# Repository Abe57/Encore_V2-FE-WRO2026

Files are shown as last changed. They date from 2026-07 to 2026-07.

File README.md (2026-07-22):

Encore | WRO-Futuros Ingenieros 2026 | PAN
====

Este es el repositorio oficial del equipo Encore V2. Somos representantes del colegio La Salle-Margarita en las regionales de Colón, Panamá de la World Robot Olympiad (WRO) 2026 en la categoría de Futuros Ingenieros.

La categoría de futuros ingenieros está enfocada en el diseño y la implementación de vehículos autónomos a escala. El desafío consiste en desarrollar un sistema capaz de navegar un circuito predefinido, identificando y superando obstáculos de forma autónoma mediante el procesamiento de datos de su entorno.

Esta disciplina está directamente alineada con las tendencias actuales y futuras de la industria automotriz, específicamente con el desarrollo de Sistemas Avanzados de Asistencia al Conductor (ADAS) y tecnologías de conducción autónoma. El proyecto de desarrollo exige una aplicación práctica de conceptos en áreas como la percepción ambiental, algoritmos de control y ingeniería de sistemas.

Nuestro proceso de desarrollo comenzó estratégicamente con un chasis prefabricado. Esta decisión nos permitió enfocarnos inicialmente en la integración de la electrónica y el desarrollo del software de control, sin la necesidad de conocimientos avanzados en diseño 3D. Sin embargo, pronto descubrimos que este punto de partida era solo el comienzo.

El verdadero desafío de ingeniería consistió en identificar sistemáticamente las limitaciones del diseño base y rediseñar cada subsistema para cumplir con nuestras exigentes expectativas de rendimiento. Desde la optimización del peso y la mecánica hasta la re-arquitectura completa del sistema eléctrico y de control, este robot es el resultado de un ciclo continuo de pruebas, diagnósticos y mejoras.

**Revise `docs` para ver la documentación completa y detallada, este `README.md` solo presenta un resumen de cada etapa del proyecto.**

## Equipo

Foto del equipo, de izquierda a derecha **José Heráldez, Abel Herrera y Pablo González**.
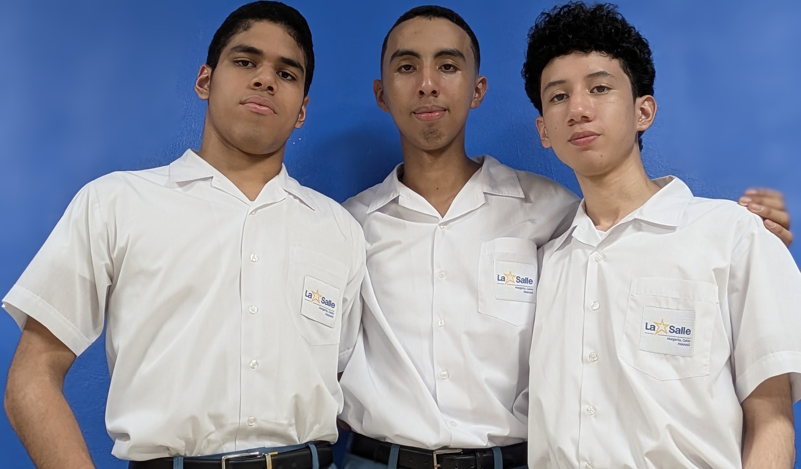
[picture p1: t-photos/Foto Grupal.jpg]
Foto equipo


## Contenido del Repositorio

* `docs` Contiene todos los documentos del equipo y el diario de ingeniería.
* `other` Otros archivos relacionados al desarrollo del robot.
* `schemes` Contiene los esquemas electromecánicos del vehículo y otros diagramas.
* `src` Contiene todos los programas que se estarán usando en la competencia.
* `t-photos` Contiene 2 fotos grupales (una formal y una divertida) y las fotos individuales.
* `v-photos` Contiene las 6 fotos desde todos los ángulos.
* `video` Contiene el video de demostración del funcionamiento del robot.

## Generalidades del robot

### 1. Vista Lateral Derecha
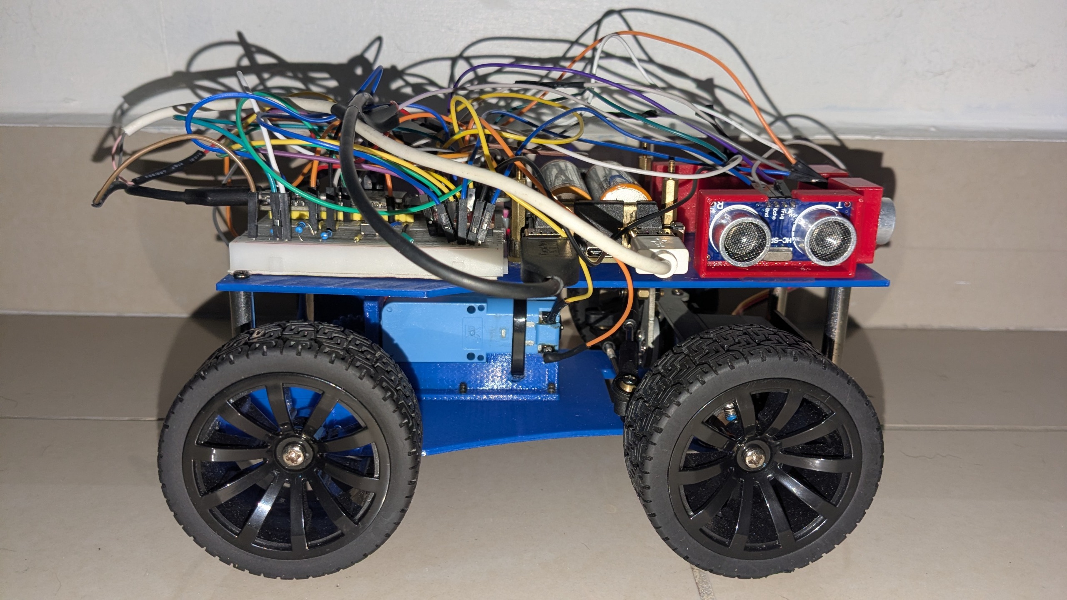
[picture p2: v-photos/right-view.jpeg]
Vista lateral derecha

*Vista del lado derecho del robot mostrando los componentes principales.*

### 2. Vista Frontal
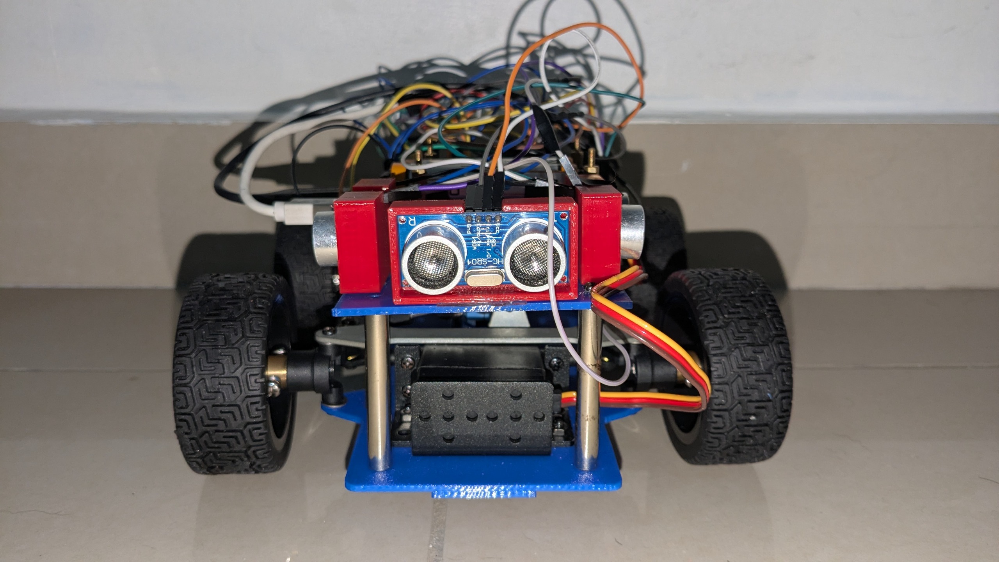
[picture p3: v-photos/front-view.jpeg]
Vista frontal

*Vista frontal del robot con los sensores de distancia y configuración delantera.*

### 3. Vista Lateral Izquierda
Vista lateral izquierda
*Vista del lado izquierdo del robot con los motores y estructura lateral.*

### 4. Vista Superior
Vista superior
*Vista desde arriba mostrando la distribución de componentes electrónicos y conexiones.*

### 5. Vista Trasera
Vista inferior
*Vista desde atras mostrando la transmisión.*

### 6. Vista Inferior
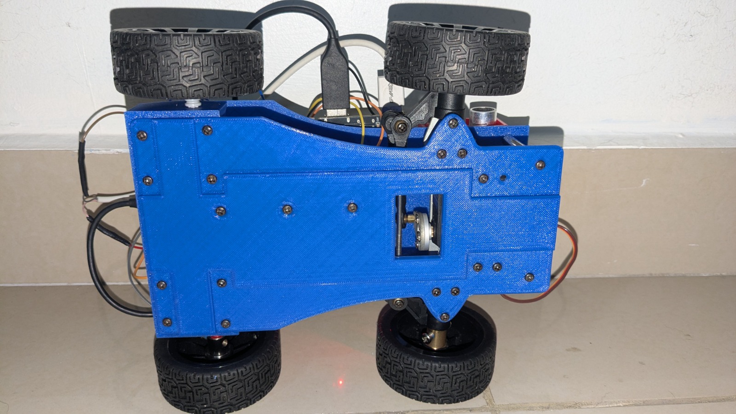
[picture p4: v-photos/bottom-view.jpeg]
Vista inferior

*Vista desde abajo mostrando la tornilleria y refuerzos estructurales.*

### Configuración general

El desarrollo del robot partió de un chasis Ackerman prefabricado para establecer una base mecánica sólida y acelerar el prototipado. Sin embargo, este punto de partida se convirtió en el primer desafío de ingeniería, ya que el diseño original presentaba problemas significativos de peso y una configuración de propulsión y dirección que requería un rediseño completo para cumplir con los objetivos de rendimiento del equipo.

### Descripción del chasis

El chasis original de metal, aunque resistente, elevaba el peso total del robot a 1700 g, una masa excesiva que limitaba la agilidad y sobrecargaba el sistema de propulsión. Para resolver esto, se llevó a cabo un proceso de optimización de materiales, reemplazando las placas de metal por diseños impresos en 3D. Esta modificación fue un éxito, reduciendo el peso total a aproximadamente 675 g y permitiendo un diseño más limpio y optimizado con perforaciones específicas para nuestros componentes. La estructura se mantuvo en dos niveles para aislar la electrónica de las vibraciones mecánicas.

### Sistema de dirección

Para lograr una navegación precisa, se implementó una geometría de dirección Ackerman. Este sistema, que minimiza el deslizamiento de las ruedas en las curvas, fue un diseño a medida del equipo. A través de un proceso de investigación y prototipado, se fabricaron soportes y se calibraron las varillas de acoplamiento para emular la cinemática ideal. El sistema es accionado por un servomotor de alto torque, asegurando que la dirección sea firme y responda con precisión a los comandos.

### Sistema de propulsión

El diseño inicial del sistema de propulsión priorizaba la velocidad con una relación de engranajes de 9:7 (sobremarcha). Sin embargo, las pruebas demostraron que el torque resultante era insuficiente para vencer la inercia y la fricción estática, impidiendo que el robot se moviera por sí solo. Tras diagnosticar el problema, se tomó la decisión de ingeniería de invertir la relación a una de reducción 7:9. Aunque esto sacrificó la velocidad máxima, multiplicó el torque, proporcionando la fuerza de arranque necesaria para un funcionamiento autónomo y fiable.

### Diseño Eléctrico

La arquitectura eléctrica evolucionó a un sistema compacto y eficiente para maximizar la confiabilidad del robot.

* ESP32 (Unidad de control principal): Actualmente se utiliza una ESP32 única, sin Arduino adicional, como cerebro del sistema. Se encarga de ejecutar la lógica de control, leer los sensores y gestionar los actuadores.

* Driver TB6612FNG: Sustituyó al L298N y se utiliza para controlar de forma eficiente los motores, mejorando la gestión de corriente y la estabilidad del sistema.

* Sensores HC-SR04: Se emplearon tres sensores ultrasónicos en la parte frontal para detectar obstáculos y medir distancias en tiempo real.

* Giroscopio BNO055: Se incorporó para obtener mediciones de orientación y mejorar la estabilidad del movimiento y la navegación del robot.

* Servo para el manejo: Se utiliza para controlar la dirección del vehículo de forma precisa y responsiva.
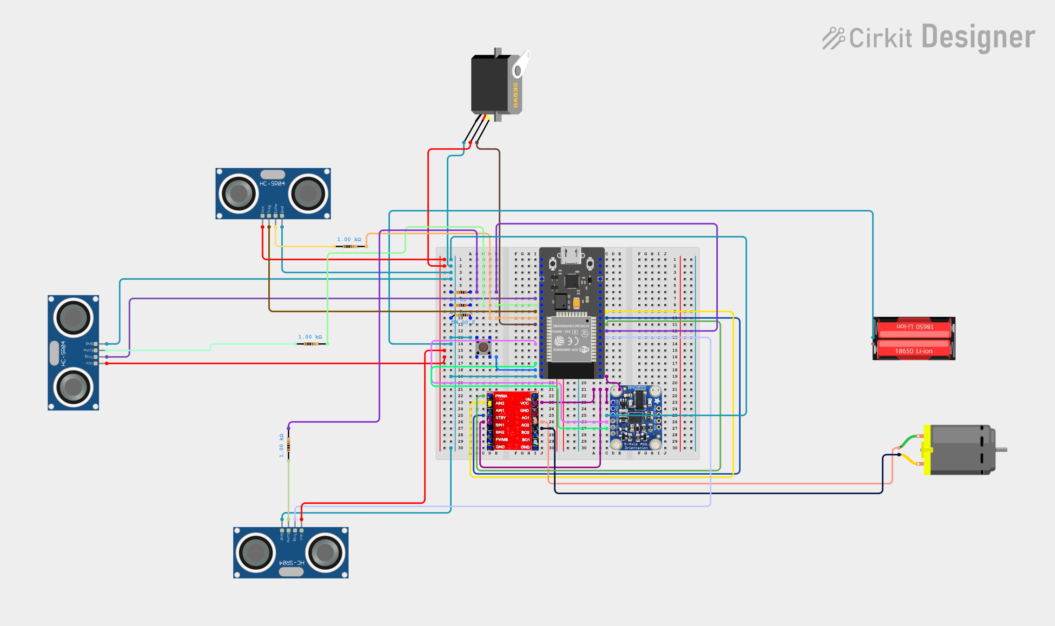
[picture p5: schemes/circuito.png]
imagen


### Gestión de la energía

La estabilidad energética se resolvió con un sistema de alimentación más simple y compacto:

* Un power bank de 10000mAh se utiliza para alimentar el motor y el servo.

* Dos baterías 18650 en conjunto proporcionan la energía necesaria para la ESP32, con salida de 5V para alimentar la unidad de control y sus periféricos. Esta configuración permite un funcionamiento estable y reduce la complejidad del sistema.

### Diseño del Código y Programación

La arquitectura del software se basa en un enfoque integrado en una sola placa de control:

* ESP32 (C++): Actúa como el cerebro principal del robot. Se encarga de la lectura de los sensores ultrasónicos, del giroscopio BNO055, de la lógica de decisión y del control de los actuadores, incluyendo los motores y el servo de dirección.

Este enfoque permite reducir la complejidad del sistema, minimizar puntos de fallo y mejorar la respuesta del robot en tiempo real.

### Demostración

Después de un arduo ciclo de desarrollo y pruebas, el robot es capaz de cumplir con los requisitos de la primera ronda, demostrando una navegación autónoma y la capacidad de detectar y esquivar obstáculos.

### Características por mejorar

Basado en los resultados de la primera competencia y las pruebas continuas, el equipo ha identificado las siguientes áreas clave para el desarrollo futuro:

* Reducir la Latencia del Bucle de Control: Optimizar el código y la comunicación interna entre la ESP32 y los actuadores para lograr reacciones más rápidas y una navegación más fluida.

* Mejorar la Fiabilidad de las Conexiones: Migrar las conexiones del protoboard a una solución más permanente, como una PCB diseñada a medida o una protoboard soldada, para eliminar los falsos contactos.

* Optimizar la Velocidad y el Control: Una vez que la fiabilidad esté garantizada, se trabajará en aumentar la velocidad máxima del robot y en refinar los algoritmos de control para una mayor precisión en el seguimiento de la trayectoria.

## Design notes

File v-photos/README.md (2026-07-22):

# Fotos del Robot WRO 2026

Este directorio contiene las 6 vistas principales del robot Encore V2 para la competencia WRO 2026.

## Vistas del Robot

### 1. Vista Lateral Derecha
Vista lateral derecha
*Vista del lado derecho del robot mostrando los componentes principales.*

### 2. Vista Frontal
Vista frontal
*Vista frontal del robot con los sensores de distancia y configuración delantera.*

### 3. Vista Lateral Izquierda
Vista lateral izquierda
*Vista del lado izquierdo del robot con los motores y estructura lateral.*

### 4. Vista Superior
Vista superior
*Vista desde arriba mostrando la distribución de componentes electrónicos y conexiones.*

### 5. Vista Trasera
Vista inferior
*Vista desde atras mostrando la transmisión.*

### 6. Vista Inferior
Vista inferior
*Vista desde abajo mostrando la tornilleria y refuerzos estructurales.*

## Componentes Principales Visibles

- Plataforma de chassís azul
- Motor DC con ruedas de tracción
- Sistema de sensores ultrasónicos HC-SR04
- Microcontrolador ESP32
- Baterías 18650 y módulo de distribución de potencia
- Cableado de conexión

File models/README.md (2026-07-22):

# Modelos 3D del robot

Este directorio contiene los diseños principales impresos en 3D del robot, incluyendo las estructuras base, los soportes de motor y eje, así como los soportes para los sensores ultrasónicos.

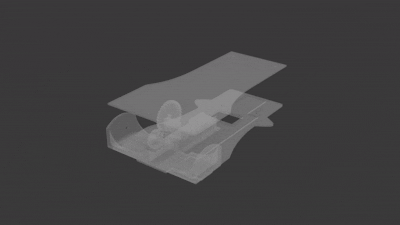
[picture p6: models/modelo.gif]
Modelo


## 1. Placa inferior
La placa inferior es la estructura base del robot. Presenta huecos para los tornillos del servo, los soportes, el soporte del motor y el soporte del eje. En su parte inferior cuenta con una extrusión que cubre la mayor parte de la placa, lo que le proporciona mayor grosor y estabilidad en las zonas donde más se necesita.

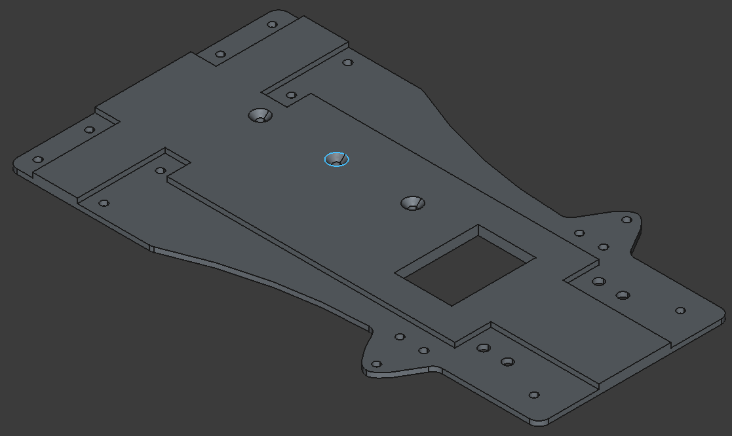
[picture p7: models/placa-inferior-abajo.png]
Placa inferior


## 2. Placa superior
La placa superior se conecta con la placa inferior mediante soportes, formando la estructura principal del chasis y permitiendo una distribución ordenada de los componentes del robot.

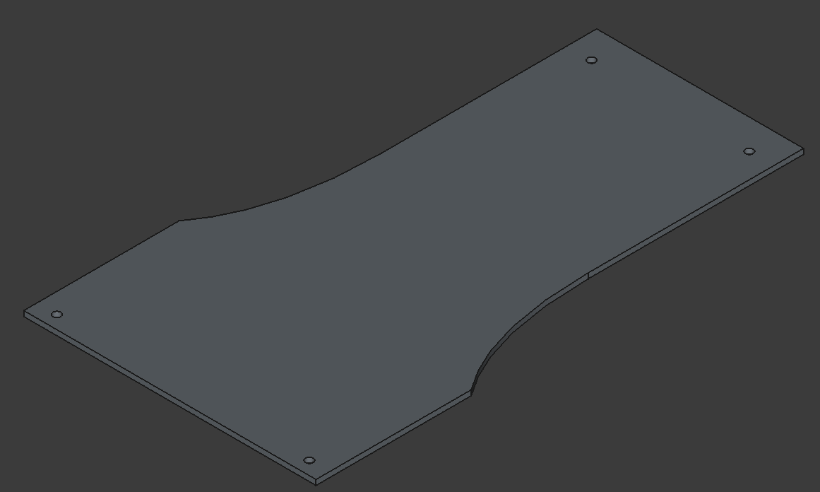
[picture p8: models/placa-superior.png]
Placa superior


## 3. Soporte del motor
El soporte del motor se atornilla directamente sobre los huecos diseñados en la placa inferior. Su función es mantener el motor en la posición óptima para un funcionamiento estable y eficiente.

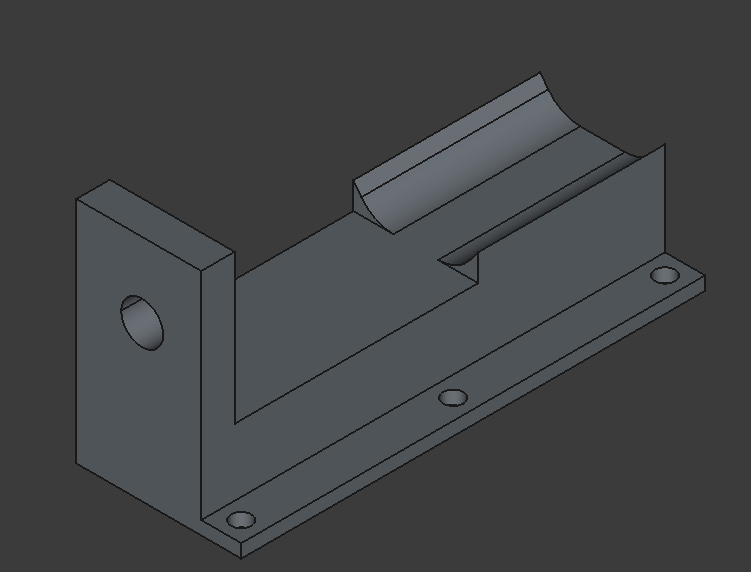
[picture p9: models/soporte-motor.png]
Soporte del motor


## 4. Soporte del eje
El soporte del eje sostiene el eje de manera que el engrane del eje y el engrane del motor giren de forma sincronizada. Está diseñado con soportes y bisagras para mejorar su resistencia y estabilidad.

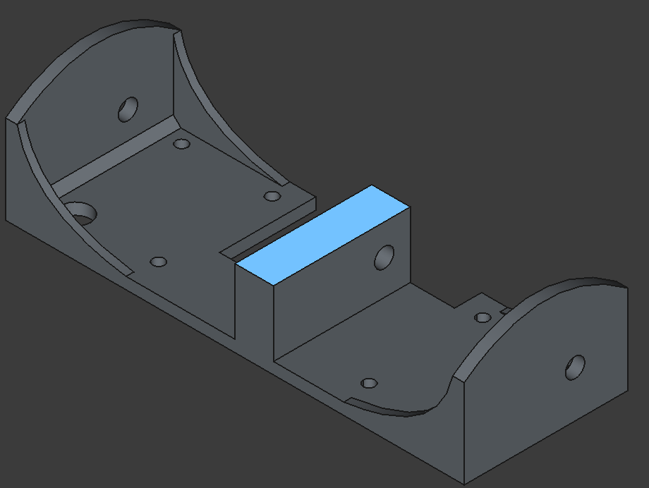
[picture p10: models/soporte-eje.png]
Soporte del eje


## 5. Soporte HC-SR04
Los soportes para los sensores HC-SR04 fueron obtenidos a partir del modelo de Printables: https://www.printables.com/model/657026-hc-sr04-ultrasonic-sensor-holder-for-orp. Estos soportes se colocan en la parte frontal del robot para sostener los sensores de forma segura y estable.

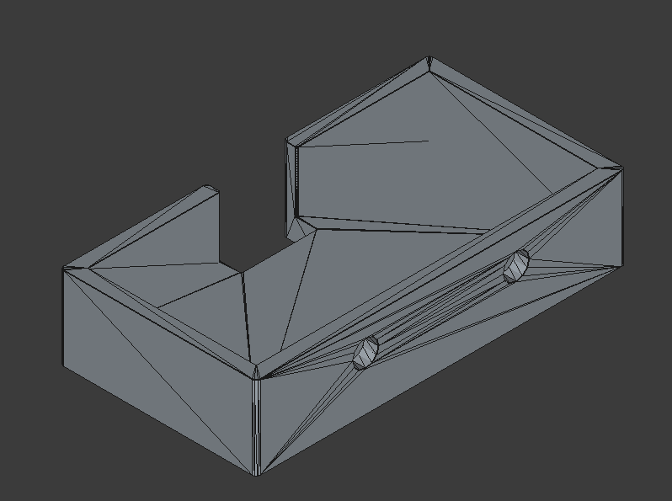
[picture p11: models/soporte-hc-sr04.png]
Soporte HC-SR04


## Engranes utilizados
Los engranes utilizados en el sistema de transmisión son de 36 dientes y 28 dientes de LEGO.

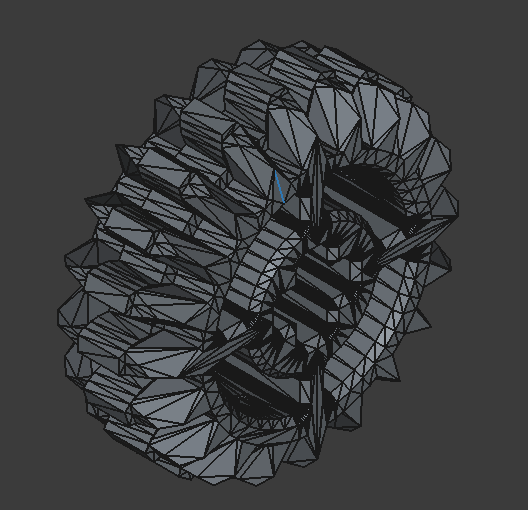
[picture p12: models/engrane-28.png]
Engrane 28 dientes


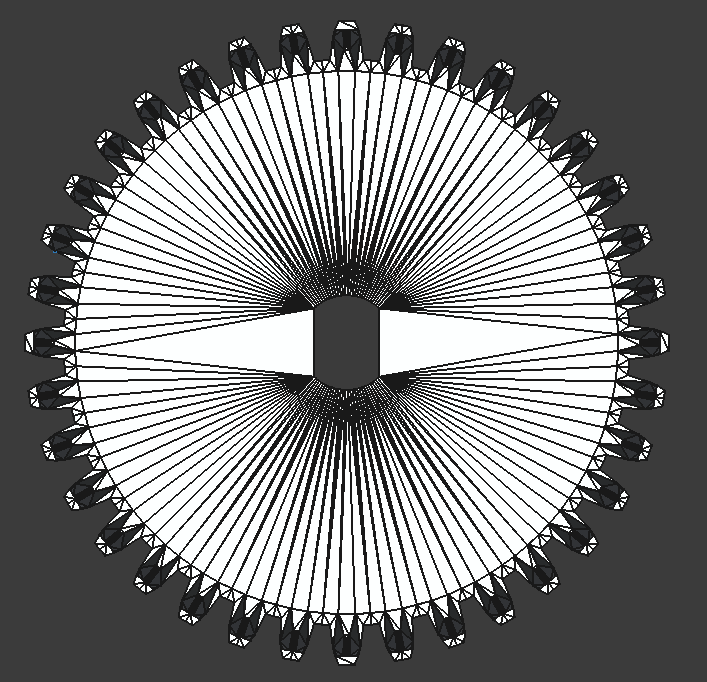
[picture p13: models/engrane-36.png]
Engrane 36 dientes


## Modificación del engrane de 36 dientes
El engrane de 36 dientes fue modificado para volverse sólido por dentro y adaptarse al motor, lo que mejora su compatibilidad y resistencia dentro del sistema mecánico.

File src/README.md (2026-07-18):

Control software
====

Este directorio contiene el software de control del vehículo utilizado para la competencia. El código principal se encuentra en el archivo `src/main/main.ino` y está pensado para operar de forma autónoma mediante sensores de distancia y un giroscopio.

## Descripción general

El programa implementa un sistema de control distribuido en dos tareas concurrentes ejecutadas en distintos núcleos del microcontrolador:

- `getSensors`: lee continuamente los sensores de proximidad y el giroscopio, y actualiza los valores de navegación usados por la lógica de control.
- `control`: gestiona la dirección del vehículo y toma decisiones para evitar obstáculos detectados por los sensores.

## Hardware involucrado

El sketch está diseñado para trabajar con:

- 3 sensores ultrasónicos (izquierdo, centro y derecho)
- Un giroscopio BNO055
- Un servomotor para la dirección
- Un driver de motores y dos pines de control de movimiento
- Un botón de inicio

## Funcionamiento del sistema

1. Al encender el sistema, se inicializan los sensores y el servo.
2. El programa espera a que se presione el botón de inicio.
3. Una vez iniciado, el robot intenta avanzar mientras el sensor central no detecte un obstáculo.
4. Si el sensor central detecta un objeto dentro del rango configurado, el sistema inicia una maniobra de giro.
5. La dirección se ajusta según la lectura del giroscopio para mantener una trayectoria controlada.
6. El algoritmo usa los sensores laterales para decidir si girar en sentido horario o antihorario.

## Variables principales

- `dMin` y `dMax`: rangos de distancia usados para detectar obstáculos y decidir cuando girar.
- `MAX_TURN`: límite de giro del servo.
- `cw`: indica la dirección del giro actual.
- `turnOffset`: ayuda a mantener el ángulo de referencia durante la maniobra.

## Notas de implementación

- El código utiliza `FreeRTOS` mediante `xTaskCreatePinnedToCore` para ejecutar tareas en núcleos separados.
- La comunicación serial se usa para depurar y monitorear los valores de los sensores en tiempo real.
- El servo se controla con la librería `ServoEasing`.

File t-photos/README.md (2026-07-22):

Fotos del Equipo
====

Foto del equipo **(De izquierda a derecha: Jose Heraldez, Abel Herrera, Pablo Gonzalez)**

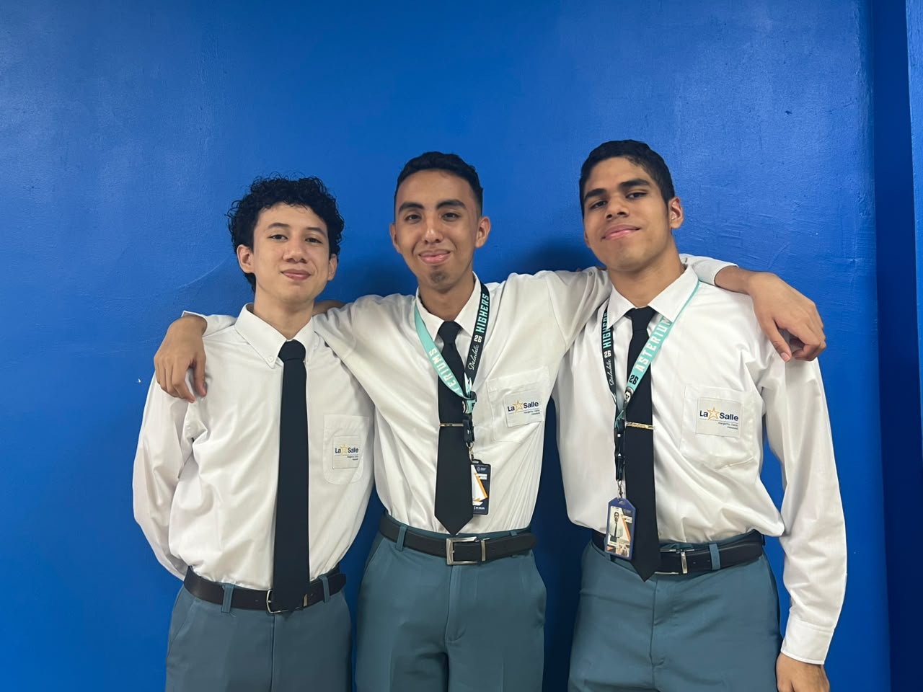
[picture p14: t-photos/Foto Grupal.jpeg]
Imagen Grupal Foto Grupal

Somos un grupo de amigos apasionados por la robotica y que cursamos el mismo grado, llevamos en las WRO desde 2023, este año vamos con el objetivo de sacar nuestro máximo potencial.

### José Heráldez
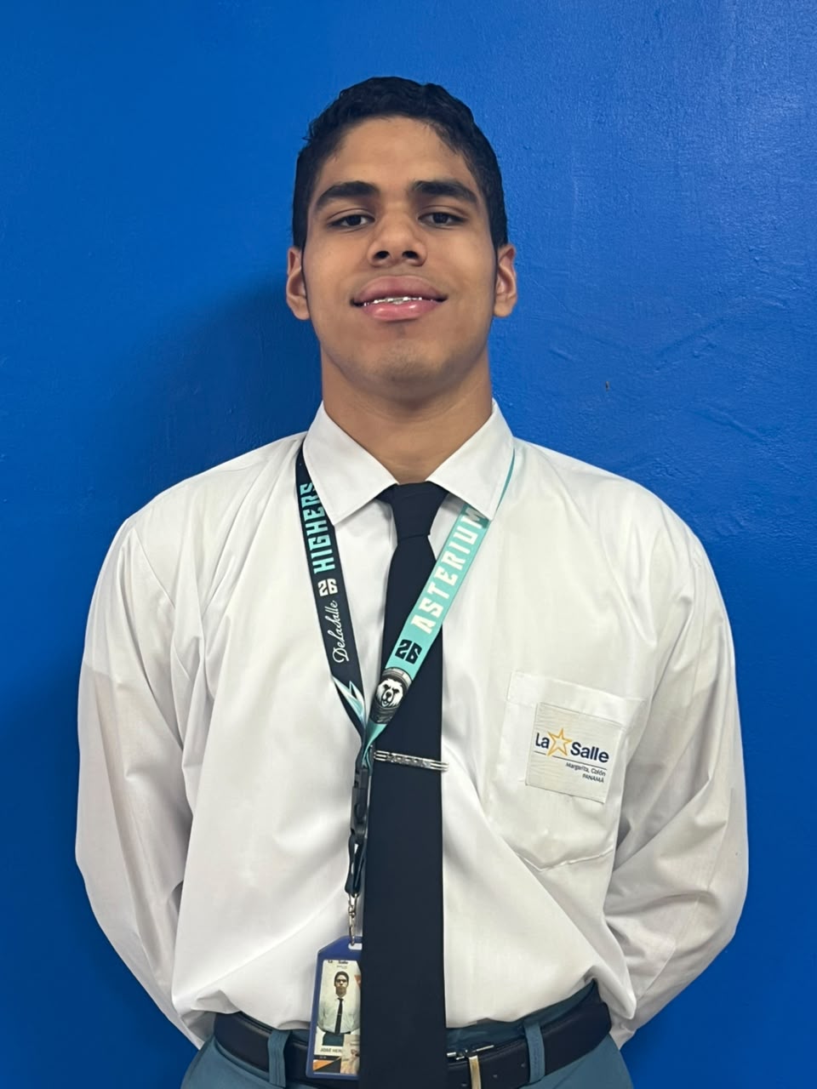
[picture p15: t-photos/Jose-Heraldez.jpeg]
José Heráldez


Es el coordinador y el apoyo general, se encarga de mantener toda la organización, reuniones, recopilación de información y redacción, es calmado, proactivo y tiene experiencia en gestión de proyectos y le gusta mantener el orden. 

### Abel Herrera
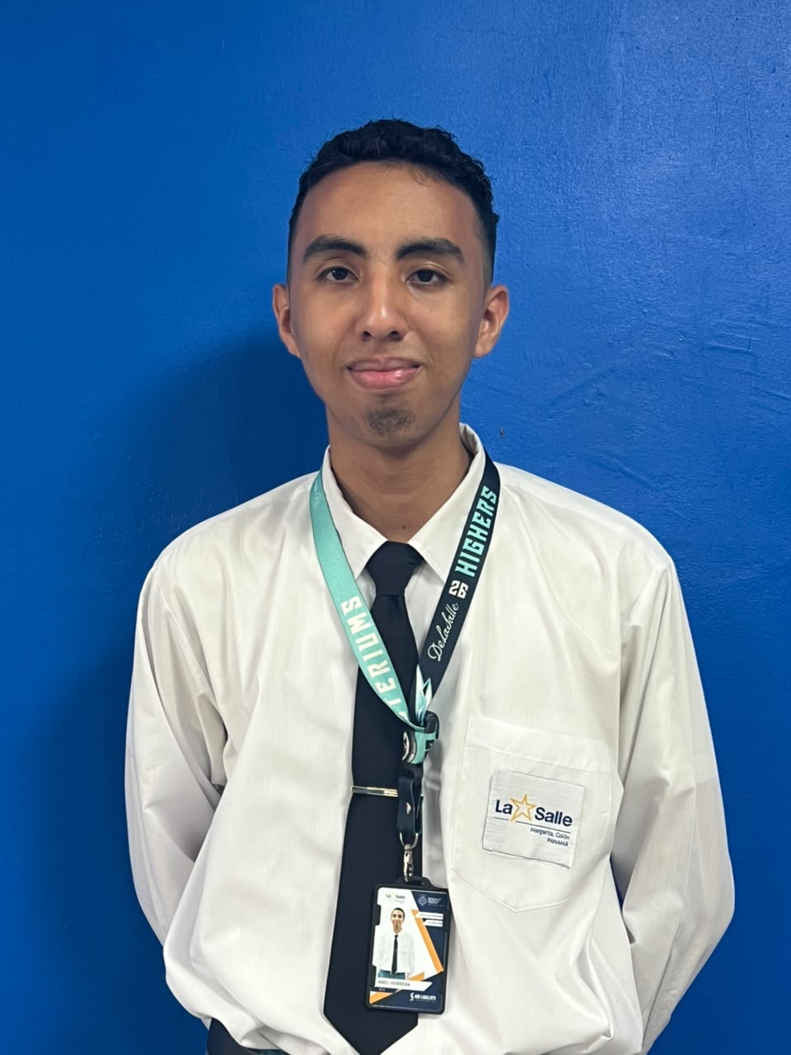
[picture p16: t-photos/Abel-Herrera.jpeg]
Abel Herrera

Es el programador del equipo, está enfocado en todo el codigo y la lógica detras de este. Le apaciona la resolucion de problemas y aprender. 

### Pablo González
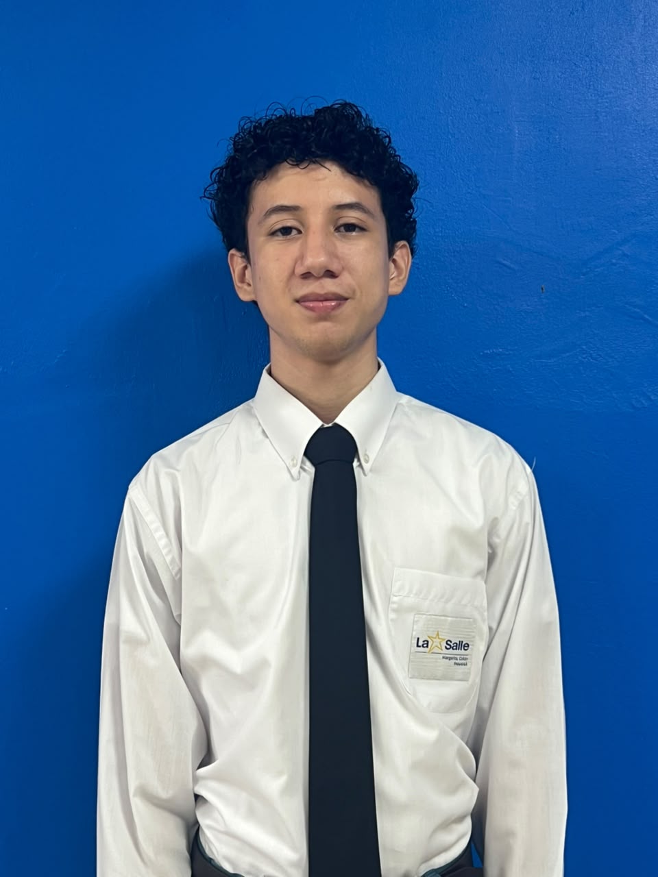
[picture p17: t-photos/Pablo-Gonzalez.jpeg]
Pablo González

Es el encargado de la parte mecánica y electrónica del robot, le gusta mantener el equipo motivado, dormir, escuchar música y le apasiona ingeniería.

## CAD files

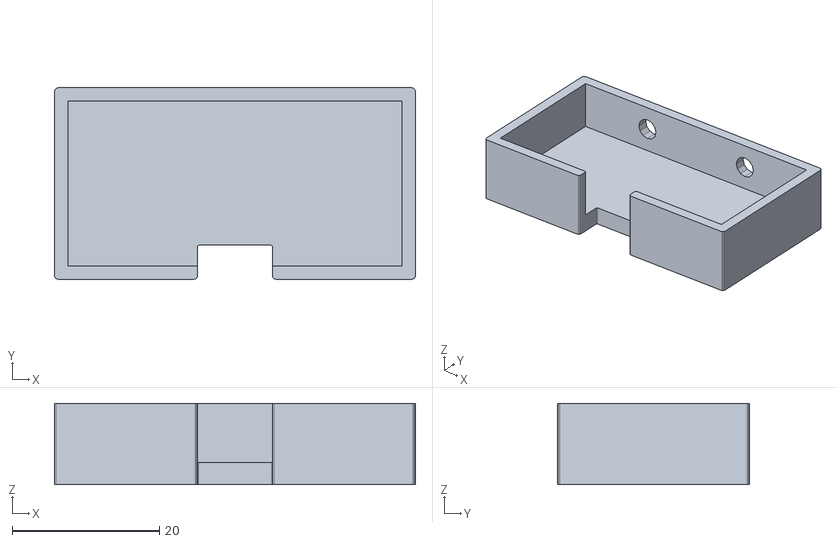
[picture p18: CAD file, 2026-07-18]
models/HC-SR04_holder.stl
49.0 x 26.0 x 11.0

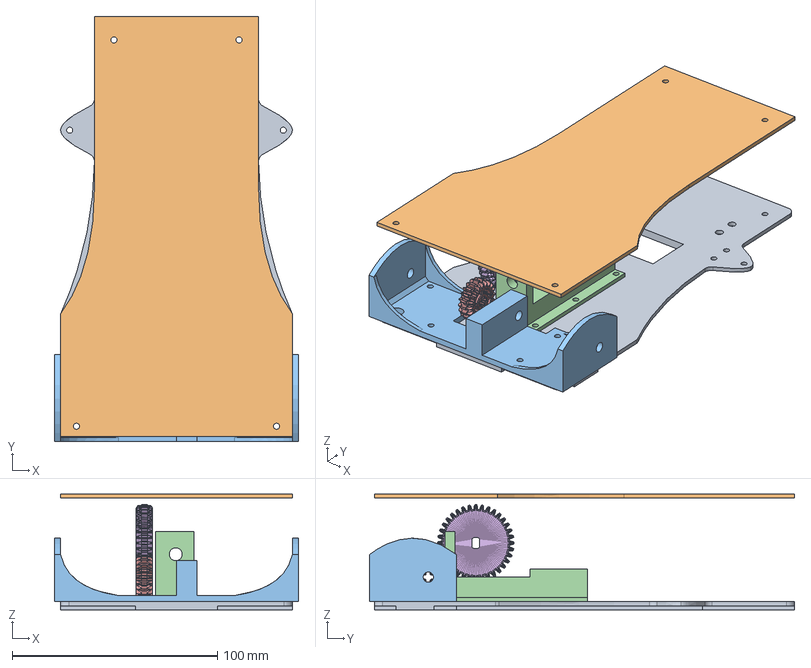
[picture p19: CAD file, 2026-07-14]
models/Car Parts.FCstd
119.0 x 207.4 x 56.5 mm
Cuerpo
Cuerpo001
Cuerpo002
Cuerpo003
gear_021
Cuerpo004

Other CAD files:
models/Car Parts.stl

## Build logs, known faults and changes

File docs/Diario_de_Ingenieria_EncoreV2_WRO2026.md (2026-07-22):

# DIARIO DE INGENIERÍA - EQUIPO ENCOREV2
## World Robot Olympiad (WRO) 2026 - Categoría Futuros Ingenieros (Vehículos Autónomos)

---

## 0. Datos generales del equipo

| Campo | Detalle |
|---|---|
| Nombre del equipo | EncoreV2 |
| País / Región | Panamá |
| Temporada | WRO 2026 |
| Categoría | Futuros Ingenieros (Carros Autónomos) |
| Entrenador | Octavio Herrera |
| Miembros | Abel Herrera - Programador / Desarrollo de software, algoritmia y CAD<br>José Heráldez - Arquitecto de sistemas, diseño eléctrico, electrónica y documentación<br>Pablo González - Diseño mecánico, impresión 3D y ensamblaje |

---

## 1. Resumen ejecutivo

El equipo EncoreV2 desarrolló su vehículo autónomo para la temporada WRO 2026 a partir de una revisión crítica del modelo 2025, cuyo chasis híbrido de acrílico cortado por caladora y piezas metálicas de kit comercial pesaba 1217 g y presentaba fricción excesiva en su tren de engranajes de Lego, lo que le impedía completar las tres vueltas reglamentarias dentro del límite de 2 minutos.

Para 2026 se rediseñó el robot bajo una filosofía de **simplificación inteligente y manufactura aditiva**: chasis monocasco impreso en 3D, tren de engranajes personalizado (36T:28T) también impreso, y consolidación del procesamiento en un único microcontrolador ESP32 de doble núcleo (eliminando el par Raspberry Pi + Arduino de la temporada anterior). El resultado es un vehículo de aproximadamente 675 g (–44.5 % de masa), que conserva el sistema de dirección Ackermann de la temporada anterior tras validar que su geometría seguía siendo óptima, permitiendo concentrar el tiempo de desarrollo en el nuevo tren motriz, la estructura y el software.

Este diario documenta no solo el diseño final, sino el **proceso**: los prototipos fallidos, las mediciones tomadas con pie de rey, los rediseños forzados por pruebas físicas, y el razonamiento detrás de cada decisión de componente.

---

## 2. Introducción, contexto y objetivos

### 2.1 Contexto del desafío WRO 2026
El desafío de Futuros Ingenieros exige un vehículo completamente autónomo que recorra una pista delimitada, evada obstáculos (pilares rojos y verdes que exigen rebase por la derecha e izquierda respectivamente) y realice un estacionamiento autónomo al final del recorrido. El robot está limitado a 300 mm × 200 mm × 300 mm y 1.5 kg.

### 2.2 Objetivos del proyecto
1. **Reducción de peso y fricción** - bajar de 1217 g a menos de 700 g mediante optimización topológica en CAD e impresión 3D.
2. **Minimización de latencia lógica** - consolidar el procesamiento en una sola MCU para una respuesta inmediata del servo ante los sensores.
3. **Optimización de consumo y estabilidad eléctrica** - aislar las líneas de potencia y lógica para evitar caídas de tensión ("voltage sags") que afecten al servo.
4. **Heredabilidad y validación de diseño** - reutilizar de forma justificada (no por comodidad) los subsistemas que ya funcionaban, para concentrar el tiempo de desarrollo en lo que realmente lo necesitaba.

### 2.3 Restricciones del proyecto (constraints)
- **Peso:** ≤ 1.5 kg (objetivo interno: <700 g).
- **Dimensiones:** 300 × 200 × 300 mm.
- **Tiempo por vuelta:** 3 vueltas dentro de una ventana de 2 minutos.
- **Tolerancia de manufactura:** los agujeros de tornillos impresos en 3D no admitían más de ±1 mm de error respecto a las medidas reales, tomadas con pie de rey.
- **Presupuesto:** los componentes se seleccionaron balanceando desempeño contra costo (p. ej. IMU de gama alta vs. sensores económicos con drift).
- **Tiempo del equipo:** al conservar la dirección heredada se liberó tiempo crítico para enfocarse en el tren motriz y el software.

---

## 3. CRITERIO 1 - Movilidad y diseño mecánico

### 3.1 Filosofía de chasis: de acrílico a monocasco impreso en 3D

El chasis 2025 era una base híbrida de acrílico cortado por láser combinada con piezas de un kit comercial tipo Ackermann metálico. El equipo evaluó dos rutas para 2026: **(a)** continuar modificando el chasis de acrílico, o **(b)** rediseñarlo por completo en impresión 3D.

## Encore Chassis

| 2025 | 2026 |
|---|---|
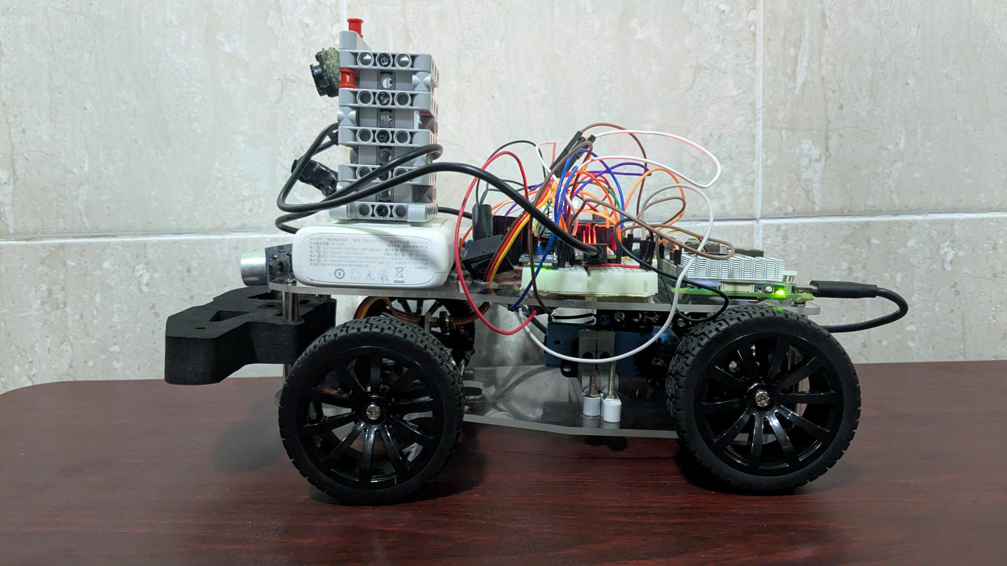
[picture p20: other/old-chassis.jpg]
|  |  |
| Chasis híbrido de acrílico y metal | Chasis monocasco impreso en 3D |
| Mayor fricción en el tren de engranajes | Tren de engranajes personalizado y menor fricción |
| Peso total 1217 g | Peso total ≈675 g |
| Diseño basado en kit comercial | Diseño optimizado a medida |

Se optó por **(b)** por tres razones concretas, validadas durante el proceso:
- **Reducción de peso**, que a su vez reduce la fuerza que el motor necesita ejercer para impulsar el robot.
- **Mayor densidad de componentes**: al poder diseñar soportes a medida, se integraron más elementos electrónicos y mecánicos en menos espacio, haciendo al robot más compacto y ágil en curvas cerradas.
- **Iteración rápida**: un rediseño en CAD podía imprimirse como pieza funcional corregida en menos de 2 horas (caso del soporte del motor), algo imposible con corte láser + ensamblaje metálico.

### 3.2 Piezas impresas en 3D: proceso de diseño, prueba y rediseño

Todas las piezas fueron dimensionadas tomando medidas reales con **pie de rey** y trasladándolas al sistema CAD. Este fue, en palabras del propio equipo, uno de los procesos más exigentes del proyecto: el margen de error admisible en los agujeros de tornillo era de apenas 1 mm, ya que un error mayor impedía que el tornillo entrara.

#### 3.2.1 Placa inferior (base principal)
Base estructural impresa a partir de una placa de referencia previa. Sostiene el "primer piso" del robot: motor de tracción y servomotor de dirección.

#### 3.2.2 Placa superior
Sostiene los componentes electrónicos (el "segundo piso" del robot: ESP32, driver de motor, sensores).

#### 3.2.3 Soporte de llantas traseras - **iteración documentada**
- **Versión 1 (fallida):** los dos soportes del eje trasero se diseñaron como piezas **independientes**, sin conexión estructural entre sí.
- **Problema detectado en pruebas:** al usar las vigas en cruz de Lego como eje de propulsión, la falta de conexión estructural permitía que el eje se doblara bajo carga, generando fricción y rozamiento que desgastaba rápidamente la base.
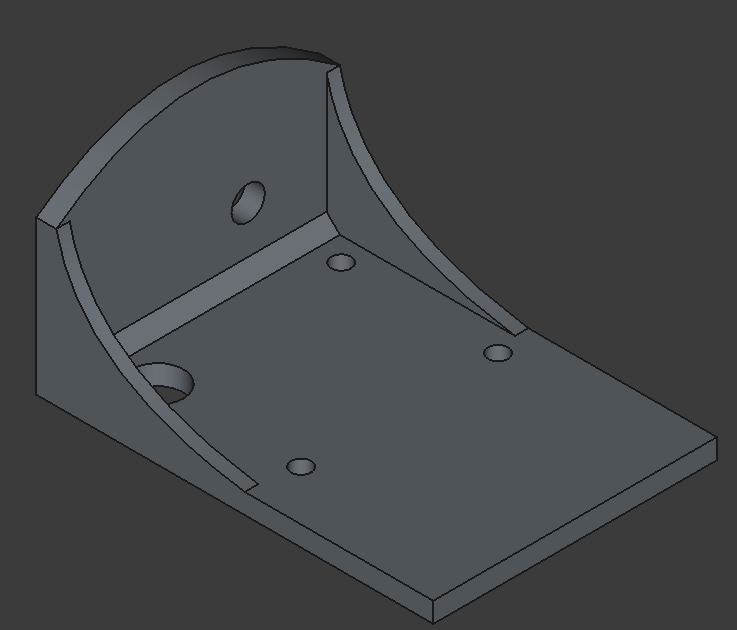
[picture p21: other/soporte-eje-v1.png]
soporte1

- **Versión 2 (solución):** se unieron estructuralmente ambos soportes y se añadió un **punto de apoyo adicional en el punto medio del eje** (en vez de solo dos puntos de apoyo en los extremos, que concentraban la mayor flexión justo en el centro). Esto incrementó significativamente la rigidez del eje transversal y permitió que el motor ejerciera mayor fuerza sin que el eje se doblara.
soporte2

#### 3.2.4 Base del motor - **la pieza que más iteración requirió**
Sin ninguna referencia previa de diseño (el motor no cuenta con tornillos propios para fijarse directamente), el equipo tuvo que idear un sistema de sujeción a partir de las pequeñas muescas del propio motor:
- Se diseñó una **pared con un orificio guía** para impedir que el motor se desplazara hacia adelante y el engranaje se saltara por encima del eje.
- Se le dio forma de "cama" con **cuñas laterales** para impedir el desplazamiento lateral.
- Se añadieron **3 tornillos en línea** para fijación directa a la placa inferior.
- Como refuerzo final, se incorporó un **tornillo pasante adicional que atraviesa la base del motor por encima del propio motor**, dándole una solidez muy superior a la esperada inicialmente y permitiendo ejercer mayor fuerza sin que el conjunto se desplace.

Para poder atornillar la base del motor sobre la zona ya reforzada de la placa inferior (ver sección 3.3, ensanchada a 4 mm), se utilizó la función de **barrido (sweep) para tornillos** del software CAD, generando una perforación cónica de 2 mm que deja el margen exacto para que el tornillo se asiente entre ambas piezas.

#### 3.2.5 Engranajes personalizados - **iteración documentada**
Se optó por imprimir los engranajes en 3D en lugar de comprarlos, por dos razones: **versatilidad** (réplicas rápidas y baratas) y **adaptación específica** a la forma peculiar del eje de salida del motor.
- El acople al eje del motor se midió con pie de rey y se modeló su geometría exacta (arcos incluidos).
- **Primer intento de impresión:** salió demasiado ajustado (pequeño) y no embonaba.
- **Segundo intento:** se aumentó ligeramente la tolerancia dimensional y el engranaje embonó perfectamente.
- El engranaje motriz (36 dientes) está basado en la geometría de un engranaje Lego de 36 dientes; el engranaje del eje (28 dientes) se diseñó con un enganche en cruz compatible con los ejes cruciformes de Lego.
- Al ser una **pieza de desgaste**, tener el archivo listo para imprimir permite reemplazo rápido y económico sin depender de piezas Lego originales, que son más costosas.

#### 3.2.6 Soportes de sensores ultrasónicos
Ver sección 4.3 (se documenta junto con la arquitectura de sensores, ya que la motivación es de confiabilidad de medición, no solo mecánica).

### 3.3 Refuerzo estructural de la placa inferior - **iteración por modo de falla**

**Problema detectado:** con un espesor uniforme de 2 mm (necesario para que los tornillos no sobresalieran), la placa inferior **flexaba** bajo peso y movimiento. Esto era peligroso porque, al pasar sobre un montículo o irregularidad de la pista, la placa podía rozar el piso y **atascar al robot**, dejándolo inmovilizado sin posibilidad de continuar la prueba.

**Solución:** se aplicó un **ensanche localizado de +2 mm** (para un total de 4 mm) únicamente en las zonas por donde pasan los tornillos estructurales importantes - **con la excepción explícita de la zona de tornillos de la base del motor**, donde el espesor debía mantenerse en 2 mm porque los tornillos disponibles (4 mm) no permitían atornillar correctamente sobre una base más gruesa (ver solución de barrido cónico en sección 3.2.4).

**Resultado:** la rigidez estructural aumentó considerablemente; ahora se requiere una fuerza significativamente mayor para deformar la placa, y la deformación residual es mínima. Este fue un ciclo completo de ingeniería: **problema detectado en pista → hipótesis → rediseño → prueba → validación**.

### 3.4 Sistema de dirección Ackermann - heredado y adaptado (no heredado por comodidad)

El mecanismo de dirección (servomotor de alto torque + bandeja metálica + varillas de transmisión ajustables, geometría Ackermann) se conservó del modelo 2025 tras un análisis explícito de costo-beneficio:

1. La geometría Ackermann del año anterior cumplía correctamente con el radio de giro mínimo exigido por las esquinas del circuito, sin inducir derrape en las llantas delanteras.
2. La bandeja metálica ofrecía una rigidez ante impactos de baja intensidad muy superior a lo que se podría lograr en una primera iteración impresa en 3D.
3. Rediseñar la dirección desde cero habría introducido variables mecánicas nuevas y consumido tiempo crítico que el equipo decidió invertir en el nuevo tren motriz y en el software.

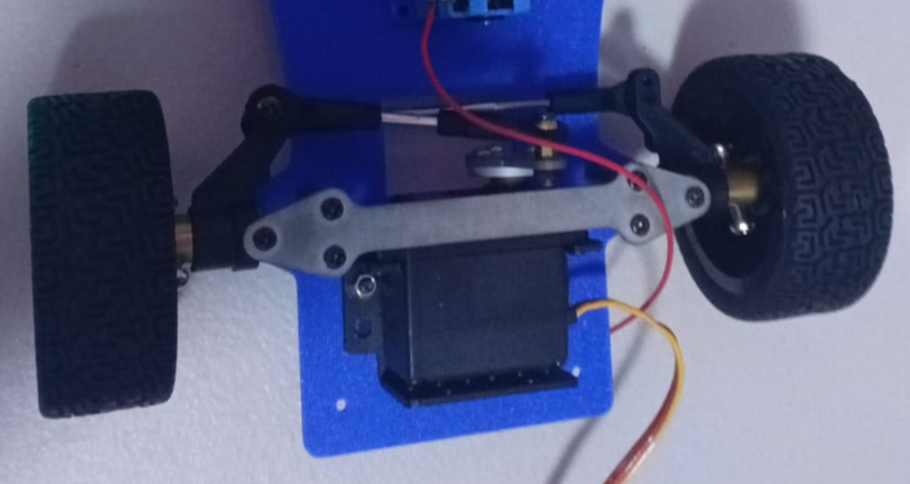
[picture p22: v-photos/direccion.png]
direccion


**Iteración de integración necesaria:** al montar la dirección heredada sobre el nuevo chasis monocasco, las pruebas revelaron que el servomotor **golpeaba la base inferior** al girar en ciertos ángulos. La causa era la ausencia de espacio libre debajo del servo. **Solución:** se añadió una **ventana rectangular** en la placa inferior, exactamente en la zona de barrido del servo, eliminando la interferencia sin comprometer la resistencia estructural de la placa (gracias al ensanche de sección 3.3).

### 3.5 Tren motriz: relación de engranajes y análisis de par/velocidad

| Elemento | Valor |
|---|---|
| Engrane conductor (motor) | 36 dientes |
| Engrane conducido (eje trasero) | 28 dientes |
| Relación de transmisión (i) | 36/28 ≈ 1.285:1 (sobremarcha / *overdrive*) |

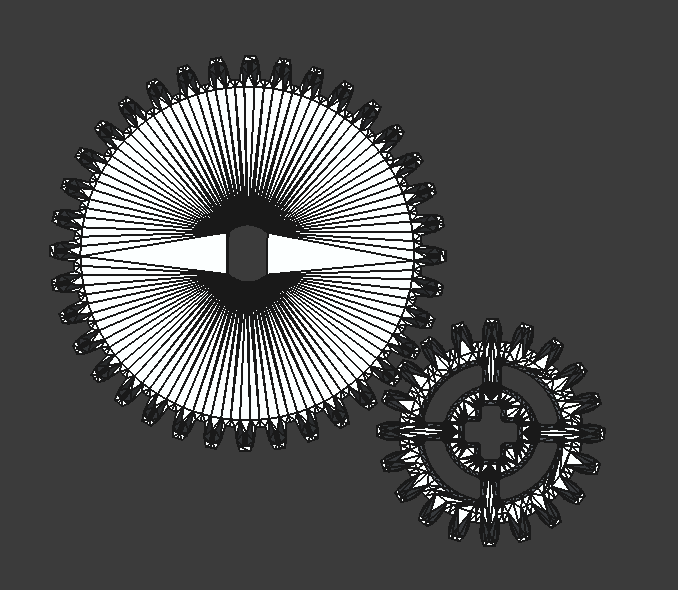
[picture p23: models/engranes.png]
engranes


**Razonamiento de par vs. velocidad (trade-off explícito):**
El equipo probó ambas configuraciones:
- **Relación inversa (reducción, mayor par):** el robot se movía con mucha más fuerza disponible, pero a una velocidad insuficiente para completar las tres vueltas dentro del límite de 2 minutos.
- **Relación de sobremarcha 36:28 (mayor velocidad):** al ser el robot ya muy ligero (≈675 g), no se requiere una reducción de torque alta para vencer la inercia inicial. El motor trabaja holgado y desarrolla una velocidad lineal alta y constante.

**Decisión:** se sacrificó fuerza disponible por velocidad, aceptando que el motor debe trabajar más exigido, a cambio de cumplir la ventana de tiempo de la prueba. Esta es una compensación de diseño consciente, no una elección por defecto.

### 3.6 Tabla de compensaciones de diseño (trade-offs mecánicos)

| Decisión | Se ganó | Se sacrificó |
|---|---|---|
| Chasis monocasco 3D vs. acrílico + kit metálico | Menor peso, mayor densidad de componentes, iteración en <2h | Menor resistencia a impactos directos que el metal |
| Relación de engranajes 36:28 (overdrive) | Velocidad suficiente para cumplir el límite de 2 min | Mayor demanda de fuerza al motor |
| Soporte de eje conectado + apoyo central | Mayor rigidez, menor desgaste | Mayor complejidad de impresión que la versión independiente |
| Ensanche estructural de +2 mm | Rigidez, robot no se atasca en pendientes | Peso adicional localizado |
| Dirección heredada (no rediseñada) | Tiempo de desarrollo liberado para tren motriz y software | Integración física no trivial (interferencia con placa, resuelta en sección 3.4) |

---

## 4. CRITERIO 2 - Arquitectura de potencia y sensores

### 4.1 Selección de componentes: comparativas y justificación

#### Microcontrolador: ESP32 WROOM 32D
Se comparó explícitamente contra dos alternativas antes de decidir:

| Opción | Por qué se descartó / eligió |
|---|---|
| Arduino (descartado) | Memoria reducida, un solo núcleo (no permite paralelizar sensores y control), menor velocidad de procesamiento, menos pines disponibles, menor versatilidad general. |
| Raspberry Pi (descartada) | Consumo eléctrico elevado para la autonomía requerida; capacidades de cómputo muy superiores a lo necesario (sobre-ingeniería); no es un microcontrolador de tiempo real, por lo que habría requerido un esquema maestro-esclavo adicional (el problema exacto que se buscaba eliminar de la arquitectura 2025). |
| **ESP32 (elegido)** | Doble núcleo real: permite ejecutar la lectura de sensores y el control del servo/motor como **dos hilos simultáneos independientes**, mejorando la velocidad de toma de decisiones - algo crítico para esta categoría. |

Con el firmware actual, el ESP32 utiliza únicamente **~11 % de su memoria disponible**, dejando margen amplio para lógica adicional (redundancia, mayor velocidad de procesamiento) sin necesidad de cambiar de MCU.

#### Sensor de orientación: IMU Adafruit BNO055 (9 GDL)
El equipo evaluó sensores giroscópicos más económicos antes de decidirse por el BNO055 (~US$40):
- Los sensores económicos presentaban **drift** (deriva del error acumulado) y lecturas poco precisas.
- El BNO055 incluye un **procesador de fusión de sensores integrado**, entrega una orientación absoluta, con precisión de decimales de grado, y **sin drift perceptible**.
- Beneficio secundario no obvio: al no requerir cálculo de compensación de deriva, se **libera carga de procesamiento del ESP32**, que de otro modo tendría que ejecutar ese cálculo en cada ciclo.

**Trade-off aceptado:** mayor costo del componente a cambio de eliminar una fuente completa de error sistemático y de reducir la carga computacional del microcontrolador.

#### Sensores de distancia: 3× HC-SR04 (ultrasónicos)
Distribuidos en **abanico** (izquierdo, centro, derecho). Esta disposición fue elegida porque cubre exactamente las zonas de decisión necesarias: detección de pared frontal (parada de emergencia / inicio de giro) y detección de apertura de carril a izquierda o derecha (definición del sentido de giro).

#### Servomotor de dirección
Alto torque, acoplado directamente a la varilla metálica de dirección heredada. Se priorizó el torque y la velocidad de respuesta porque el algoritmo de navegación depende de que el giro máximo se ejecute de inmediato al detectar el borde del carril (ver sección 5.3).

#### Motor de tracción DC
Se eligió un micro-motor DC estándar por ser la opción más económica y de instalación más simple del catálogo evaluado (solo requiere dos cables de alimentación, sin protocolo de control adicional).

#### Controlador de motor: TB6612FNG vs. L298N
Se comparó explícitamente contra el controlador L298N (más común y económico):

| Controlador | Evaluación |
|---|---|
| L298N | Funcional, pero basado en transistores BJT que generan una **caída de tensión interna significativa**, reduciendo el voltaje real entregado al motor y, por tanto, el torque/velocidad máximos disponibles. |
| **TB6612FNG (elegido)** | Basado en MOSFET, con una caída de tensión interna mucho menor, entregando al motor una fracción mayor del voltaje nominal de la batería. |

**Decisión:** se eligió el TB6612FNG porque el objetivo de velocidad del tren motriz (sección 3.5) depende directamente de entregarle al motor el máximo voltaje disponible; el L298N habría anulado parcialmente la ganancia de velocidad obtenida con la relación de engranajes overdrive.

### 4.2 Distribución eléctrica y aislamiento de ruido

En la temporada 2025, la integración conjunta de Raspberry Pi y Arduino sufría caídas de tensión inesperadas por el consumo simultáneo del motor de tracción y el servomotor en el mismo bus eléctrico. Para 2026 se diseñó una distribución con **dos rieles físicamente separados**:

1. **Riel de potencia (línea ruidosa):** 7.4 V nominales (2× Li-Ion 18650 en serie) directo al driver TB6612FNG (VM) y al servomotor. Estos elementos de alto consumo e inducción magnética quedan aislados de la parte lógica.
2. **Riel lógico (línea limpia de 5 V):** mediante un regulador de tensión de alta eficiencia, alimenta al ESP32, los tres sensores ultrasónicos y la IMU BNO055.
3. **Punto común de tierra:** el GND de potencia y el GND de lógica se unen en un único nodo central, evitando bucles de tierra ("ground loops") que corromperían las señales digitales del ESP32.

**Modo de falla detectado y corregido durante pruebas:** con el circuito armado en protoboard sin esta separación, el servomotor presentaba **temblores erráticos** cada vez que el motor DC arrancaba (ruido inductivo acoplado a la línea lógica). Se resolvió aplicando la separación estricta de líneas descrita arriba.

*(Diagrama de cableado: ver imagen incluida en la sección 8 / repositorio GitHub.)*

### 4.3 Montaje de sensores ultrasónicos - **iteración por confiabilidad**

- **Versión inicial:** los sensores ultrasónicos se fijaban con cinta adhesiva directamente sobre la base.
- **Problema:** esta fijación no era permanente, dificultaba mantener el ángulo exacto necesario para cada sensor, y se desplazaba con el uso.
- **Solución:** se diseñaron **soportes impresos en 3D de ajuste a presión**, específicos para el HC-SR04, que fijan el sensor en un ángulo constante y permiten conexión/desconexión rápida sin perder la calibración angular.
- **Resultado:** eliminación del problema de desplazamiento; las mediciones ahora presentan buena estabilidad repetida.

### 4.4 Alimentación y autonomía

- 2× celdas Li-Ion 18650 en serie (2S, 7.4 V nominales): se eligieron por su buena relación voltaje/potencia/capacidad de carga para aplicaciones de robótica.
- Un par de baterías sostiene entre 1 y 2 horas de pruebas continuas.
- El equipo mantiene **dos pares adicionales de celdas 18650 de respaldo** para no interrumpir sesiones de prueba largas.

---

## 5. CRITERIO 3 - Arquitectura de software y estrategia de obstáculos

### 5.1 Consolidación de procesamiento multihilo en ESP32

Se eliminó la comunicación serie (UART) entre Raspberry Pi y Arduino Nano de la arquitectura 2025. El firmware corre nativamente en un solo ESP32 sobre **FreeRTOS**, dividiendo la carga en dos hilos que corren en núcleos separados:

- **Core 0 - Hilo de sensores (`getSensors`):** se ejecuta cada 50 ms (20 Hz). Lee secuencialmente los tres sensores ultrasónicos (izquierdo, centro, derecho) y adquiere de forma continua la orientación de la IMU BNO055.
- **Core 1 - Hilo de control (`control`):** corre con prioridad máxima. Evalúa las variables globales actualizadas por el hilo de sensores y ajusta la posición del servomotor (librería `ServoEasing`) y la dirección del motor de tracción vía el driver TB6612FNG.

Esta separación en dos núcleos fue la motivación central para elegir el ESP32 sobre Arduino (núcleo único) en primer lugar - ver sección 4.1.

### 5.2 Diagrama de flujo del sistema

```mermaid
flowchart TD
    subgraph SETUP["1. Inicialización del sistema - Core 1"]
        A[Inicio del ESP32] --> B[Inicializar comunicación I2C y Serie]
        B --> C["Configurar pines: BUTTON, PWM, FW, BW"]
        C --> D[Inicializar sensor IMU BNO055]
        D --> E[Configurar y acoplar servo de dirección]
        E --> F{¿Se presionó BUTTON?}
        F -- No --> F
        F -- Sí --> G[Crear hilo getSensors · Core 0]
        G --> H[Crear hilo control · Core 1]
    end

    subgraph SENSORS["2. Hilo de sensores - Core 0"]
        I[Inicio getSensors] --> J[Fijar orientación base de la IMU]
        J --> K[Adquirir evento de orientación]
        K --> L["Calcular guiñada acumulada (updateYaw)"]
        L --> M["Leer HC-SR04: izquierdo, centro, derecho"]
        M --> N["Calcular ángulo objetivo:<br>angToMatch = ini_angle + turnOffset·90·cw"]
        N --> O[Esperar 50 ms]
        O --> K
    end

    subgraph CONTROL["3. Hilo de control - Core 1"]
        P[Inicio control] --> Q["Encender motor: FW = HIGH, PWM = HIGH"]
        Q --> R{"¿center > dMin?"}
        R -- Sí --> S{"¿cw == 0?"}
        S -- Sí --> T{"¿left > dMax?"}
        T -- Sí --> U["cw = 1 (horario)"]
        T -- No --> V{"¿right > dMax?"}
        V -- Sí --> W["cw = -1 (antihorario)"]
        V -- No --> X[Mantener trayectoria recta]
        U --> Y[Calcular y limitar ángulo del servo]
        W --> Y
        X --> Y
        S -- No --> Y
        Y --> Z[Ajustar dirección suavemente · ServoEasing]
        Z --> AA[Esperar 100 ms]
        AA --> R
        R -- No --> AB[Incrementar turnOffset]
        AB --> AC["Girar al máximo: servo_c + MAX_TURN·cw"]
        AC --> AD{"¿accumulatedYaw <= angToMatch?"}
        AD -- Sí --> AE[Esperar 50 ms]
        AE --> AD
        AD -- No --> R
    end

    G -.-> I
    H -.-> P
    N -. actualiza variables .-> R
    L -. heading estabilizado .-> Y
    L -. heading estabilizado .-> AD
    M -. distancias .-> R
```

### 5.3 Algoritmo de navegación y evasión

1. **Detección de curva/intersección:** el robot avanza en línea recta mientras los sensores laterales (`left`, `right`) miden distancias cortas y estables a las paredes interiores. Cuando un sensor lateral detecta un aumento súbito de distancia (por encima del umbral `dMax`, calibrado en 150 cm), se interpreta que el carril se abrió hacia ese lado.
2. **Definición del sentido de giro (`cw`):** `left > dMax` → sentido horario (`cw = 1`); `right > dMax` → sentido antihorario (`cw = -1`).
3. **Seguimiento de guiñada (yaw) sin discontinuidad:** la IMU entrega orientación absoluta 0°–359°. Para evitar el salto brusco al cruzar de 359° a 0° (que generaba virajes erráticos del servo), se implementó `updateYaw()`, que acumula el delta angular corrigiendo el cruce de frontera:
   - `Δ = ángulo_actual − ángulo_anterior`
   - si `Δ < -180°` → `Δ += 360°`; si `Δ > 180°` → `Δ -= 360°`
   - `ángulo_acumulado += Δ`
4. **Acción del servo:** el ángulo se ajusta de forma suavizada con `ServoEasing` hacia el objetivo, limitado a ±40° respecto al centro, para evitar picos de torsión que dañen el chasis impreso.
5. **Limitador de seguridad (sensor central):** si `center < dMin` (calibrado en 20 cm, ajustado a 40 cm tras pruebas), el software interrumpe la trayectoria recta e inicia el giro máximo inmediato en la dirección determinada, previniendo colisión frontal.

### 5.4 Pruebas y ajuste (tuning)

Durante el desarrollo se identificaron y corrigieron tres problemas mediante prueba física en pista (detalle completo en sección 7.5 - Historial de iteraciones):
- Calibración inicial de `dMax` generaba giros anticipados antes de llegar a las esquinas reales; se recopiló telemetría por WiFi (solo en fase de depuración, deshabilitada en competencia) y se reajustó el umbral hasta que el robot solo activara la lógica de curva al salir por completo de la zona de muros rectos.
- El umbral `dMin` se ajustó de 20 cm a 40 cm tras observar en pista que 20 cm dejaba muy poco margen de reacción.

---

## 6. CRITERIO 4 - Pensamiento sistémico y decisiones de ingeniería

### 6.1 Restricciones explícitas del proyecto
Peso máximo (1.5 kg, meta interna <700 g) · dimensiones (300×200×300 mm) · ventana de tiempo (2 min / 3 vueltas) · tolerancia de manufactura 3D (±1 mm en agujeros de tornillo) · espesor máximo de placa compatible con tornillería disponible (2 mm, salvo zonas reforzadas) · presupuesto de componentes (p. ej. IMU de alto costo justificado, motor DC económico sin justificación adicional necesaria) · tiempo de desarrollo del equipo (dirección no rediseñada para liberar horas hacia tren motriz y software).

### 6.2 Interacción entre subsistemas

El sistema se piensa como cuatro subsistemas interdependientes:

- **Mecánico** (chasis, tren motriz, dirección) define la masa e inercia que el subsistema de **potencia** debe mover, y el espacio físico disponible para el subsistema **electrónico**.
- **Potencia/electrónica** (baterías, driver, riles aislados) determina cuánta fuerza y estabilidad de señal recibe el subsistema **mecánico** (motor, servo) y el **software**.
- **Sensores** (ultrasónicos + IMU) alimentan directamente al **software** de navegación, y su ubicación física depende de decisiones tomadas en el subsistema mecánico (espacio en la placa inferior, soportes impresos).
- **Software** cierra el ciclo, traduciendo lecturas de sensores en comandos hacia motor y servo, cuya respuesta física depende, de nuevo, del diseño mecánico (rigidez, ausencia de flexión) y eléctrico (sin ruido, sin caídas de tensión).

Ejemplo concreto de esta interdependencia documentado en este diario: el ensanche estructural de la placa inferior (mecánico, sección 3.3) tuvo que dejar una excepción explícita en la zona de tornillos de la base del motor porque la tornillería disponible (eléctrico/mecánico) no lo permitía - una restricción de un subsistema condicionando la solución de otro.

### 6.3 Decisiones de ingeniería

| # | Decisión | Razonamiento |
|---|---|---|
| 1 | ESP32 en lugar de Arduino + Raspberry Pi | Se necesitaba paralelismo real (dos hilos) sin el consumo eléctrico ni la complejidad de una Raspberry Pi, ni las limitaciones de memoria/velocidad/núcleo único de un Arduino. |
| 2 | IMU BNO055 en lugar de un giroscopio económico | El drift de los sensores baratos introducía error acumulado inaceptable para el seguimiento de guiñada; el costo adicional (~US$40) se justifica por eliminarlo por completo y liberar cómputo del ESP32. |
| 3 | Driver TB6612FNG en lugar de L298N | El L298N reduce el voltaje entregado al motor por caída interna en sus transistores; el objetivo de velocidad (relación overdrive) exigía entregar el máximo voltaje posible. |
| 4 | Relación de engranajes overdrive (36:28) en lugar de reducción | Se priorizó cumplir la ventana de tiempo de 2 minutos sobre maximizar el torque disponible. |
| 5 | Chasis monocasco 3D en lugar de acrílico + kit metálico | Se priorizó reducción de peso e iteración rápida sobre la resistencia a impacto directo que ofrecía el metal. |
| 6 | Conservar la dirección Ackermann heredada en lugar de rediseñarla | Ya cumplía el radio de giro requerido y ofrecía rigidez estructural probada; rediseñarla habría consumido tiempo crítico sin beneficio claro. |
| 7 | Soportes de sensores ultrasónicos impresos a presión en lugar de cinta adhesiva | Se priorizó estabilidad y repetibilidad de la medición sobre la simplicidad de montaje inicial. |

### 6.4 Modos de falla identificados y mitigación

| Modo de falla | Causa raíz | Mitigación aplicada |
|---|---|---|
| Desgaste acelerado de engranajes PLA | Fricción térmica contra el eje de latón del motor | Lubricante de alta viscosidad + rediseño de tolerancia/módulo de diente en CAD |
| Flexión del eje trasero | Soportes de llanta independientes, sin conexión estructural | Conexión estructural entre soportes + apoyo central en el eje |
| Flexión de la placa inferior en pendientes (riesgo de robot atascado) | Espesor uniforme de 2 mm insuficiente | Ensanche localizado a 4 mm en zonas críticas |
| Servomotor golpeando la base inferior al girar | Ausencia de espacio libre bajo el servo en el chasis monocasco | Ventana rectangular en la placa inferior |
| Motor desplazándose y engranaje saltando el eje | Motor sin tornillería propia de fijación | Pared con orificio guía + cuñas laterales + 3 tornillos en línea + Zip Tie pasante |
| Temblor errático del servo al arrancar el motor | Ruido inductivo acoplado entre línea de potencia y línea lógica | Separación física de rieles + nodo de tierra común |
| Mediciones ultrasónicas inestables | Fijación con cinta adhesiva, ángulo no constante | Soportes impresos de ajuste a presión |
| Drift en orientación | Sensores giroscópicos económicos | Selección de IMU BNO055 con fusión de sensores integrada |
| Giros anticipados antes de la esquina real | Umbral `dMax` mal calibrado | Recolección de telemetría WiFi (solo depuración) + reajuste del umbral |
| Viraje errático al cruzar 359°→0° | Discontinuidad matemática del ángulo absoluto | Función `updateYaw()` con acumulación corregida |

### 6.5 Historial de iteraciones (ciclo planear → construir → probar → mejorar)

1. **Iteración 1 - Desgaste de engranajes:** prototipos en PLA fallan por fricción térmica → lubricante + rediseño de tolerancia.
2. **Iteración 2 - Latencia/ruido eléctrico:** temblor del servo al arrancar el motor → separación estricta de líneas lógicas y de potencia en la protoboard.
3. **Iteración 3 - Calibración de sensores de distancia:** `dMax` provocaba giros anticipados → telemetría WiFi de depuración + reajuste del rango dinámico.
4. **Iteración 4 - Soporte de llantas traseras:** de independiente (con flexión) a conectado con apoyo central.
5. **Iteración 5 - Base del motor:** de un primer diseño insuficiente a un sistema de pared + cuñas + tornillo pasante.
6. **Iteración 6 - Engranaje motriz:** primer intento de impresión demasiado ajustado → segundo intento con tolerancia aumentada.
7. **Iteración 7 - Rigidez de la placa inferior:** flexión detectada en pista → ensanche localizado de +2 mm.
8. **Iteración 8 - Montaje de sensores ultrasónicos:** de cinta adhesiva a soporte impreso a presión.
9. **Iteración 9 - Integración de la dirección heredada:** interferencia servo-chasis detectada en pista → ventana rectangular en la placa inferior.

---

## 7. Cumplimiento del reglamento WRO 2026

1. **Dimensiones y peso:** el robot cumple 300×200×300 mm y, con ≈675 g, se mantiene muy por debajo del límite de 1.5 kg.
2. **Propulsión de eje único:** tracción trasera por caja de engranajes acoplada mecánicamente + dirección Ackermann de un eje, sin tracción diferencial.
3. **Desactivación de conectividad inalámbrica:** el ESP32 cuenta con radio WiFi, usada exclusivamente en laboratorio para telemetría de calibración (sección 5.4/sección 6.5). El firmware de competencia incluye la directiva `WiFi.mode(WIFI_OFF)` en tiempo de compilación, deshabilitando por completo la pila WiFi para las rondas oficiales.
4. **Controles físicos:** interruptor general de energía (baterías 18650) y pulsador físico de arranque (pin digital 23). Tras una reparación en pista, el estado de calibración de la IMU permanece guardado en el programa sin necesidad de recargar código.

---

## 8. Galería de perspectivas del robot

### 1. Vista Lateral Derecha
Vista lateral derecha
*Vista del lado derecho del robot mostrando los componentes principales.*

### 2. Vista Frontal
Vista frontal
*Vista frontal del robot con los sensores de distancia y configuración delantera.*

### 3. Vista Lateral Izquierda
Vista lateral izquierda
*Vista del lado izquierdo del robot con los motores y estructura lateral.*

### 4. Vista Superior
Vista superior
*Vista desde arriba mostrando la distribución de componentes electrónicos y conexiones.*

### 5. Vista Trasera
Vista inferior
*Vista desde atras mostrando la transmisión.*

### 6. Vista Inferior
Vista inferior
*Vista desde abajo mostrando la tornilleria y refuerzos estructurales.*

---

## 9. Aspectos pendientes 
1. **PCB dedicada:** reemplazar la protoboard y los cables Dupont (riesgo de desconexión por impacto) por una placa soldada o baquelita perforada.
2. **Control de velocidad adaptativo:** implementar PWM variable mediante encoders magnéticos en el tren trasero, para desacelerar dinámicamente antes de curvas y reducir aún más el derrape.

---

## 10. Conclusiones

El desarrollo del vehículo EncoreV2 para WRO 2026 representa una revisión completa, y no cosmética, del modelo de la temporada anterior: cada subsistema -chasis, tren motriz, dirección, electrónica y software- fue evaluado, y en los casos donde se mantuvo un diseño heredado (la dirección), esa decisión está respaldada por análisis y no por omisión. El proceso documentado en este diario -desde el margen de error de 1 mm al tomar medidas con pie de rey, hasta los nueve ciclos de iteración descritos en sección 6.5- refleja un proceso de ingeniería real, con fallos, mediciones y rediseños verificables, que es precisamente lo que este repositorio busca evidenciar.

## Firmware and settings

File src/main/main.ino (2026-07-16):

#include <Wire.h>
#include <Adafruit_Sensor.h>
#include <Adafruit_BNO055.h>
#include <ServoEasing.hpp>
#include <Ultrasonic.h>

// get EVERYTHING

TaskHandle_t Sensors = NULL;
TaskHandle_t Controls = NULL;

// initialize loop objects

Ultrasonic uLeft(32,33);
Ultrasonic uCenter(4,16);
Ultrasonic uRight(17,5);

int left = 0;
int center = 0;
int right = 0;

// initialize proximity sensors
//        LEFT  CENTER  RIGHT
// TRIG |  32  |   4  |  17  |
// ECHO |  33  |  16  |   5  |

int dMin = 20;
int dMax = 150;
int cw = 0;

#define MAX_TURN 40

float rotX = 0;
Adafruit_BNO055 gyro = Adafruit_BNO055(55);
sensors_event_t event;

// initialize BNO055 rotational sensor and related

#define BUTTON 23

// start button

#define PWM 25
#define FW 26
#define BW 27

// motor control pins

int servo_c = 90;
ServoEasing Timonteo; //como te odio serbastian

// initialize servo

int ini_angle = 0;
int angToMatch = 0;
int turnOffset = 0;

// variables for direction algorithm

void getSensors(void * parameters){
  gyro.getEvent(&event);
  ini_angle = event.orientation.x;
  // get initial robot rotation

  for (;;){
    gyro.getEvent(&event);
    rotX = event.orientation.x;

    Serial.print("Gyro roll: ");Serial.println(rotX);
    Serial.println("----------------------------------");

    left = uLeft.read();
    center = uCenter.read();
    right = uRight.read();

    Serial.print("Left prox: ");Serial.print(left);Serial.println("cm");
    Serial.print("Center prox: ");Serial.print(center);Serial.println("cm");
    Serial.print("Right prox: ");Serial.print(right);Serial.println("cm");

    angToMatch = ini_angle + (turnOffset*90*cw);

    delay(50);
  }
}

void control(void * parameters){
  digitalWrite(FW,HIGH);
  digitalWrite(PWM,HIGH);
  for (;;){
    while (center > dMin){
      if (cw == 0){
        if (left > dMax){
          cw = 1;
          Serial.println("Going clockwise");
        }
        if (right > dMax){
          cw = -1;   
          Serial.println("Going counter-clockwise");
        }
      }
      // the totally awesome algorithm
      Timonteo.easeTo(constrain(servo_c + rotX - angToMatch,servo_c-MAX_TURN,servo_c+MAX_TURN));
      delay(100);
    }
    turnOffset++;
    Timonteo.easeTo(servo_c+(MAX_TURN*cw));
    Serial.println("wall detected: turn...NOW!!!!");
    while (rotX <= angToMatch) {
      delay(50);
    }
    Serial.println("We good now, keep going");
  }
}

void setup() {
  Serial.begin(115200);

  if (!gyro.begin()) {
    Serial.println("Could not find BNO055.");
    while(1);
  }
  gyro.setExtCrystalUse(true);

  Timonteo.attach(18, 90);
  Timonteo.setSpeed(170);

  pinMode(BUTTON, INPUT_PULLUP);

  pinMode(PWM, OUTPUT);
  pinMode(FW, OUTPUT);
  pinMode(BW, OUTPUT);

  Serial.println("Press button to start");
  while (digitalRead(BUTTON) == HIGH)
  {
    delay(1);
  }

  xTaskCreatePinnedToCore(
    control,
    "Car Control",
    4096,
    NULL,
    10,
    &Controls,
    1
  );
  // start control thread on core 1

  xTaskCreatePinnedToCore(
    getSensors,
    "Sensor Data",
    4096,
    NULL,
    1,
    &Sensors,
    0
  );
  // start sensors thread on core 0
}

void loop() {
}

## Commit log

2026-07-14 Basic getting sensors and setting motors. 3D Models
    [Car Parts.FCstd]
2026-07-16 Models and others
    [Car Parts.stl]
2026-07-18 Refactor code structure for improved readability and maintainability
    [HC-SR04_holder.stl]
2026-07-22 Circuit Update
